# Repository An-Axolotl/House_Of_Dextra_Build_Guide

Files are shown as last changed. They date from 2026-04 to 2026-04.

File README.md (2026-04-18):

# 🏡 House of Dextra 🦾

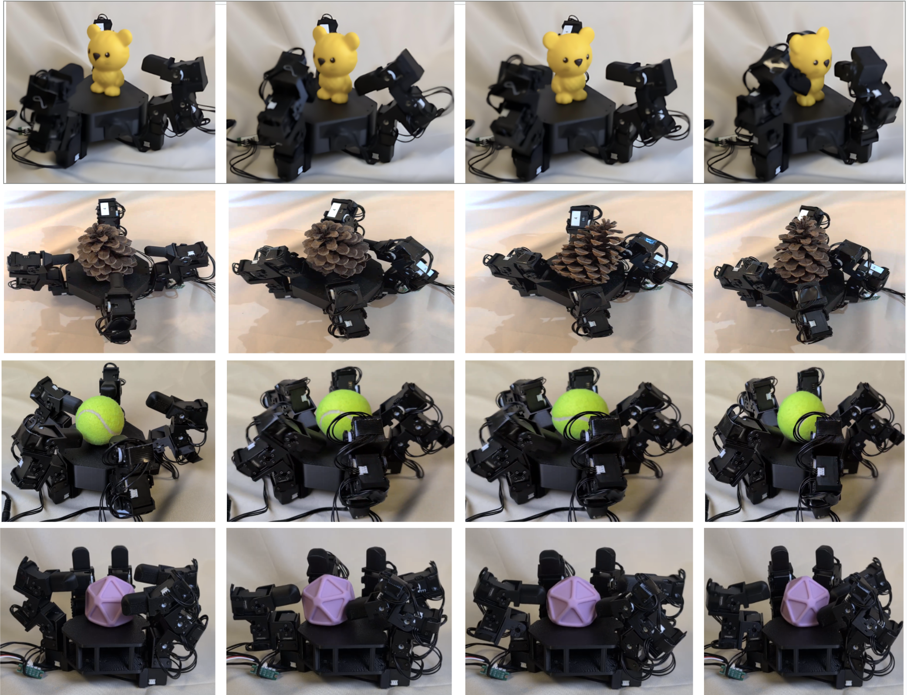
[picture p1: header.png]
House of Dextra


You can build multiple hands from one platform, here's the guide!

This guide covers how to build a modular robot hand, and how to alter it to build similar hands. Hand variants are shown on our [website](https://an-axolotl.github.io/HouseofDextra/build_guide).

**Key Features:**
- **Modular:** all electronics and components can be disassembled and re-used into other morphologies. If you are doing co-design or want to quickly prototype changes to robot hands, this is a great starting point
- **Easy to Build:** 3-4 hours to build and deploy the first hand, then less than an hour after printing for each additional robot hand
- **5 Finger Direct Drive:** 5 fingered robot hands (or 3, 4, 5, 6 fingers if you choose). Servo motors allow for easy sim-to-real since the encoders are position accurate

---

## 🛒 Bill of Materials

| Item | Quantity | Price | Notes |
|---|---|---|---|
| [Cables](https://robotis.us/robot-cable-x3p-180mm-10pcs/) | 1 | $38.42 | |
| [Expansion Boards](https://www.robotis.us/3p-jst-expansion-board/) | 2 | $13.80 | |
| [Servo Motors](https://www.robotis.us/dynamixel-xl330-m288-t/) | 20 | $549.80 | 5 finger = 20, 4 fingers = 16, 3 fingers = 12, etc. |
| [U2D2 Power Hub Board](https://www.robotis.us/u2d2-power-hub-boardset/) | 1 | $21.85 | |
| [U2D2 Communication Board](https://www.robotis.us/u2d2/) | 1 | $36.92 | |
| [Power Supply](https://www.amazon.com/ALITOVE-Converter-5-5x2-1mm-100V-240V-Security/dp/B078RT3ZPS) | 1 | $16.49 | |
| [Black PLA](https://us.store.bambulab.com/products/pla-basic-filament) | 1 | $22.99 | Makes it look cool |
| USB 3.0 | 1 | | |
| **Total** | | **$700.27** | |

**Additional tools:** Electrical tape, screwdriver kit, micro cutters (~$31). And a 3D printer that can print PLA 🤖

> **Optional:** For extra-sturdy joints, add [servo horns](https://www.robotis.us/hnx330-n101-set/) for each servo motor.

---

## 🖨️ Print Guide

Use **PLA Basic** with **auto tree branching supports** enabled. All STL files and SolidWorks parts are available **[HERE](#)** *(attach link)*.

| Part | Quantity |
|---|---|
| Palm | 1 |
| Fingertips | 5 |
| Servo Holders (connecting finger joints) | 15 |
| Lever Holders (mounting fingers to palm) | 5 |
| Servo Washers, Large | 15 |
| Servo Washers, Small | 15 |

When printing is done, remove supports with micro cutters.

---

## 🔧 Assembly

Full assembly instructions with images are at **[the build guide](https://an-axolotl.github.io/HouseofDextra/build_guide)**. At a high level:

1. Connect one servo motor vertically to the L-shaped servo holder
2. Bolt servos into each servo holder (long side down, wire ports exposed)
3. Snap large and small washers together (small inside large) and slide onto the free side of each servo
4. Mount fingertips to the top using the same process
5. Daisy-chain servo motors with X3P cables; secure wires with electrical tape
6. Bolt each assembled finger into the palm's square brackets
7. Connect four fingers to the expansion board and one directly to the U2D2 board
8. Bolt the U2D2 communication hub to the U2D2 power board, connect with one cable
9. Check wiring, plug in power, and turn on

---

## 🚀 Deployment

Install [Dynamixel Wizard](https://emanual.robotis.com/docs/en/software/dynamixel/dynamixel_wizard2/) and connect the U2D2 board via USB 3.0. Run a scan to find all motors, then:

1. **ID each motor** - number them 1-20 starting with the thumb's vertical motor as 1, working up and around each finger
2. **Verify movement** - use the torque slider in Dynamixel Wizard to confirm each motor moves
3. **Tune PID values** - go to Options and set proportional, integral, and derivative values per motor
4. **Set joint limits** - record the servo tick at each desired limit and enter them in the config file (or use the defaults provided in the code)

---

## 💻 Software

### Dependencies

```bash
pip install dynamixel-sdk numpy torch
```

Requires Python 3.8+. Motors communicate over USB via the U2D2 board (`/dev/ttyUSB0` on Linux/Mac, `COM*` on Windows).

---

### `test.py` - Hardware Verification

**Start here.** Verifies motor communication and movement without any policy. Runs a wave motion by default, where each finger bends inward then returns to rest in sequence.

```bash
python test.py --config config/anthro_standard.yaml --test-mode wave
```

**Test modes** (switch live with keyboard):

| Key | Mode | Behavior |
|-----|---|---|
| `1` | `static` | Hold default pose |
| `2` | `wave` | Wave fingers sequentially (default) |
| `3` | `sine` | Smooth sinusoidal motion on all joints |
| `4` | `incremental` | Step through predefined poses |
| `r` | | Reset to base pose |
| `Space` | | Pause / resume |
| `q` / `ESC` | | Quit (returns to base pose, disables torque) |

```
--config / -c    Path to config file   (default: config/anthro_standard.yaml)
--test-mode / -t Test mode             (default: wave)
--speed / -s     Speed multiplier      (default: 1.0)
```

If all fingers move as expected, you are good to go.

---

### `sync_midpoint_control.py` - Midpoint Oscillation Test

A self-contained lower-level test with no config file. On each keypress, toggles all finger joint motors between their midpoint and lower limit. Useful for quickly checking motor limits and PID response right after first wiring.

```bash
python sync_midpoint_control.py
```

Press any key to toggle; press `ESC` to exit. Motor IDs, limit offsets, and PID gains are hardcoded at the top of the file, edit them directly to match your hand.

> The 5 base/abduction motors (IDs 1, 5, 9, 13, 17) are held at their midpoint throughout; only the finger joint motors oscillate.

---

### `standard_control.py` - Policy Control

This script is the blueprint for running your own sim-to-real policy on the hardware. It handles the full real-time control loop: reading joint positions at the configured frequency, building a history observation, running inference on a TorchScript policy, and sending goal positions back to the motors. If you have trained a policy in simulation and want to deploy it on the hand, this is the file to adapt.

```bash
python standard_control.py \
  --config config/anthro_standard.yaml \
  --policy-path path/to/policy.pt
```

```
--config / -c      Path to config file          (default: config/anthro_standard.yaml)
--policy-path / -p Path to TorchScript .pt file (default: set in config)
```

The script sends the default pose first, then waits for a keypress to activate the policy. Loop timing stats (command Hz, read Hz, bus RTT, missed ticks) are printed every second. Press `q` or `ESC` to exit cleanly, torque is disabled automatically.

---

## 🔁 How to Adapt

- **Add/remove fingers** - Do so in motor ID order to avoid re-IDing
- **Custom palms** - Copy servo mounting brackets from the SolidWorks part onto any new geometry and export as STL
- **Custom fingertips** - Design any shape and connect on top of a lever
- **More fingers** - Add another expansion board for up to 10 fingers
- **Different materials** - PETG, TPU for flex tips, etc.

All components connect and disconnect the same way as the original assembly.

---

## 📖 Citation

If you use this in your research, please cite:

```bibtex
@article{fay2025crossembodied,
  title={House of Dextra: Cross Embodied Co-Design for Dexterous Hands},
  author={Fay, Kehlani and Djapri, Darin and Zorin, Anya and Clinton, James
          and El Lahib, Ali and Su, Hao and Tolley, Michael T. and Yi, Sha
          and Wang, Xiaolong},
  journal={arXiv preprint},
  year={2025},
  month={December}
}
```

---

*All the best, Fay* 🤖

## Motor Position Resolution
Each position tick represents 360°/4096 ≈ 0.088 degrees of rotation.

<details>
<summary><strong>Detailed Motor Configuration Settings</strong></summary>

### Motor Settings Used in Research

**Common Parameters for All Motors:**
- Moving Threshold: 10 (2.29 rev/min, unit is 0.22888 rev/min)
- Temperature Limit: 70°C
- Voltage Range: 3.5V - 7V
- PWM Limit: 100%
- Current Limit: 1750 mA
- Velocity Limit: 445 (101.85 rev/min, unit is 0.22888 rev/min)

---

#### Thumb Motors

**Motor 1:**
- Homing Offset: 0
- Min Limit: 1404 (actual: 856)
- Max Limit: 2315 (actual: 2956)
- Drive Mode: 1
- PID Gains: (1200, 100, 1500)
- Limit Offset: (+548, -641)

**Motor 2:**
- Homing Offset: 0
- Min Limit: 2048 (actual: 1990)
- Max Limit: 3072 (actual: 3370)
- Drive Mode: 1
- PID Gains: (1200, 0, 1500)
- Limit Offset: (+58, -298)

**Motor 3:**
- Homing Offset: 0
- Min Limit: 2048 (actual: 1990)
- Max Limit: 3072 (actual: 3320)
- Drive Mode: 1
- PID Gains: (2500, 0, 3000)
- Limit Offset: (+58, -248)

**Motor 4:**
- Homing Offset: 0
- Min Limit: 2048 (actual: 1990)
- Max Limit: 3072 (actual: 3340)
- Drive Mode: 1
- PID Gains: (2000, 0, 2000)
- Limit Offset: (+58, -268)

---

#### Index Finger Motors

**Motor 5:**
- Homing Offset: 0
- Min Limit: 2616 (actual: 2048)
- Max Limit: 3527 (actual: 4095)
- Drive Mode: 0
- PID Gains: (900, 180, 1500)
- Limit Offset: (+568, -568)

**Motor 6:**
- Homing Offset: 0
- Min Limit: 1024 (actual: 950)
- Max Limit: 2048 (actual: 2300)
- Drive Mode: 1
- PID Gains: (1200, 0, 2000)
- Limit Offset: (+74, -252)

**Motor 7:**
- Homing Offset: 0
- Min Limit: 2048 (actual: 1980)
- Max Limit: 3072 (actual: 3320)
- Drive Mode: 1
- PID Gains: (2500, 0, 6000)
- Limit Offset: (+68, -248)

**Motor 8:**
- Homing Offset: 0
- Min Limit: 2048 (actual: 2000)
- Max Limit: 3072 (actual: 3350)
- Drive Mode: 1
- PID Gains: (2000, 0, 2000)
- Limit Offset: (+48, -278)

---

#### Middle Finger Motors

**Motor 9:**
- Homing Offset: 0
- Min Limit: 1592 (actual: 1024)
- Max Limit: 2503 (actual: 3072)
- Drive Mode: 0
- PID Gains: (900, 0, 1500)
- Limit Offset: (+568, -569)

**Motor 10:**
- Homing Offset: 0
- Min Limit: 1024 (actual: 940)
- Max Limit: 2048 (actual: 2320)
- Drive Mode: 1
- PID Gains: (2500, 100, 6000)
- Limit Offset: (+84, -272)

**Motor 11:**
- Homing Offset: 0
- Min Limit: 2048 (actual: 1990)
- Max Limit: 3072 (actual: 3320)
- Drive Mode: 1
- PID Gains: (2000, 10, 2500)
- Limit Offset: (+58, -248)

**Motor 12:**
- Homing Offset: 0
- Min Limit: 2048 (actual: 1996)
- Max Limit: 3072 (actual: 3342)
- Drive Mode: 1
- PID Gains: (2000, 0, 2000)
- Limit Offset: (+52, -270)

---

#### Ring Finger Motors

**Motor 13:**
- Homing Offset: 0
- Min Limit: 1820 (actual: 1251)
- Max Limit: 2730 (actual: 3299)
- Drive Mode: 1
- PID Gains: (1500, 0, 1500)
- Limit Offset: (+569, -569)

**Motor 14:**
- Homing Offset: 0
- Min Limit: 1024 (actual: 960)
- Max Limit: 2048 (actual: 2300)
- Drive Mode: 1
- PID Gains: (2500, 100, 6000)
- Limit Offset: (+64, -252)

**Motor 15:**
- Homing Offset: 0
- Min Limit: 2048 (actual: 1990)
- Max Limit: 3072 (actual: 3320)
- Drive Mode: 1
- PID Gains: (2000, 10, 2500)
- Limit Offset: (+58, -248)

**Motor 16:**
- Homing Offset: 0
- Min Limit: 0 (actual: 0)
- Max Limit: 1024 (actual: 1300)
- Drive Mode: 1
- PID Gains: (2000, 0, 2000)
- Limit Offset: (0, -266)

---

#### Pinky Finger Motors

**Motor 17:**
- Homing Offset: 512
- Min Limit: 374 (actual: 0)
- Max Limit: 1285 (actual: 1854)
- Drive Mode: 0
- PID Gains: (1500, 0, 1500)
- Limit Offset: (+374, -569)

**Motor 18:**
- Homing Offset: 0
- Min Limit: 3072 (actual: 3000)
- Max Limit: 4095 (actual: 4095)
- Drive Mode: 1
- PID Gains: (2500, 100, 6000)
- Limit Offset: (+72, 0)

**Motor 19:**
- Homing Offset: 0
- Min Limit: 1024 (actual: 1285)
- Max Limit: 2048 (actual: 1787)
- Drive Mode: 1
- PID Gains: (2000, 0, 2500)
- Limit Offset: (0, -261)

**Motor 20:**
- Homing Offset: 0
- Min Limit: 2048 (actual: 1990)
- Max Limit: 3072 (actual: 3350)
- Drive Mode: 1
- PID Gains: (2000, 0, 2000)
- Limit Offset: (+98, -328)

</details>

# Installation
Run ```sudo python python/setup.py install```

# Usage
Verify control movement with ```python sync_midpoint_control.py```

Run policy with ```python run.py```

Specify a policy with ```python run.py --policy-path agents/<.pt>``` or with short form ```python run.py -p agents/<.pt>```

See more options with ```python run.py --help```

# Configuration
All configs can be found in config/config.yaml

Device name can be figured out by running:
```
pip install arduino-cli
arduino-cli core update-index
arduino-cli core install arduino:avr
arduino-cli core list
arduino-cli board list
```

# Note On Robustness
Running the policy on the real hand requires a specific default joint position that the policy was trained under. Number of observations also matters and for now these are the only observations:
1. 3 frames of <joint position normalized between [-1, 1], joint target position in radian space> 
2. One hot encoded vector for the object type between [Sphere, Cross, Cube, Cylinder]
3. Optional: Object state

Current code will need to be modified to allow for robust observation/action space based on hand design.

Also the LEAP Hand Authors chose to use the first part of the frame in [-1, 1] space while the second part is in radians space, so this may have to be changed soon too.

# References
SDK Python Scripts: 
https://emanual.robotis.com/docs/en/software/dynamixel/dynamixel_sdk/sample_code/python_read_write_protocol_2_0/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

SDK API REFERENCE:
https://emanual.robotis.com/docs/en/software/dynamixel/dynamixel_sdk/api_reference/python/

Python SDK Quick Start Guide:
https://www.youtube.com/watch?v=LAizFTTdL8o

Python SDK Walkthrough:
https://www.youtube.com/watch?v=uHnrLVZEGi4
https://www.youtube.com/watch?v=pZmueNctY0s

# Dynamixel SDK


The ROBOTIS Dynamixel SDK is a software development kit that provides Dynamixel control functions using packet communication. The API is designed for Dynamixel actuators and Dynamixel-based platforms. For more information on Dynamixel SDK, please refer to the e-manual below.
- [ROBOTIS e-Manual for Dynamixel SDK](http://emanual.robotis.com/docs/en/software/dynamixel/dynamixel_sdk/overview/)

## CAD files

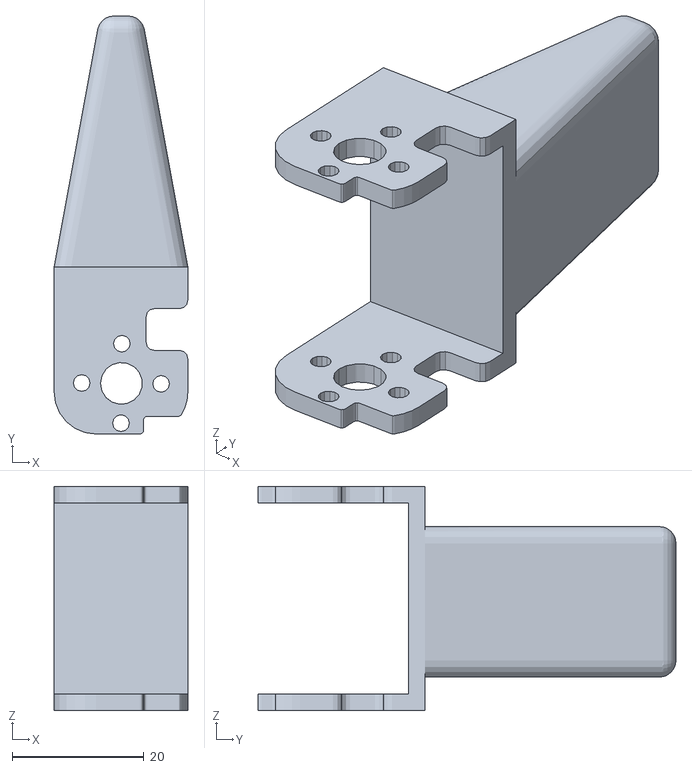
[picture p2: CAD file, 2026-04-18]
Robot_Hand_STLs/Modular Robot Hand Parts/Fingertip Options/Fingertip_Assem_Wedge.STL
20.3 x 63.5 x 34.0

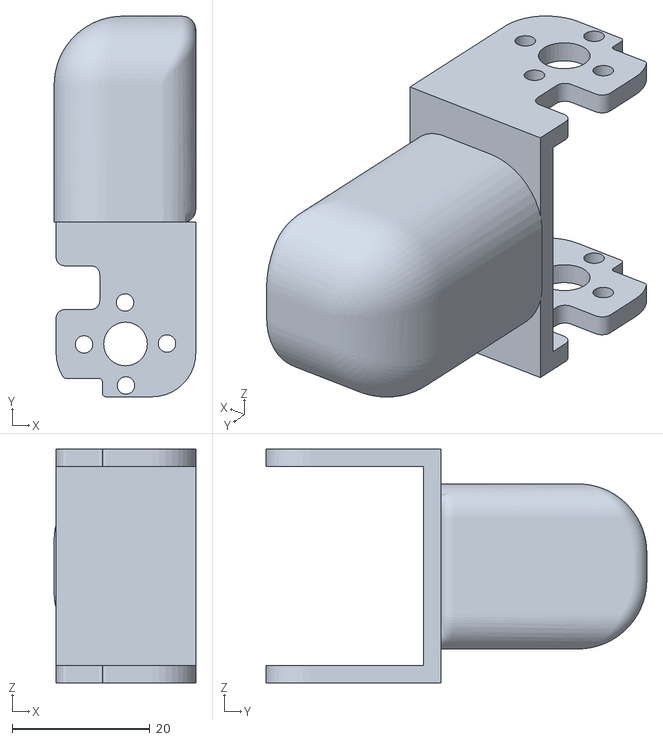
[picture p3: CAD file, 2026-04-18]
Robot_Hand_STLs/Modular Robot Hand Parts/Fingertip Options/Fingertips_Merged_from_LEAP/Fingertip_AssemLeap.STL
20.6 x 55.4 x 34.0

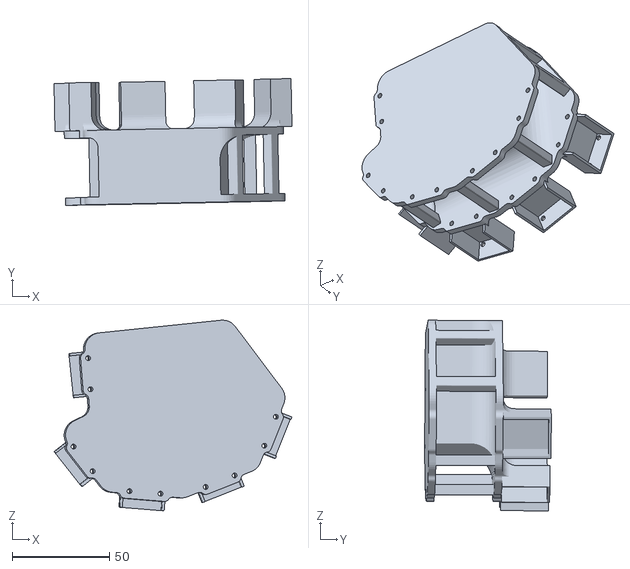
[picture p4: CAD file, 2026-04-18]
Robot_Hand_STLs/Modular Robot Hand Parts/Palm_assem.STL
122.2 x 65.1 x 97.9

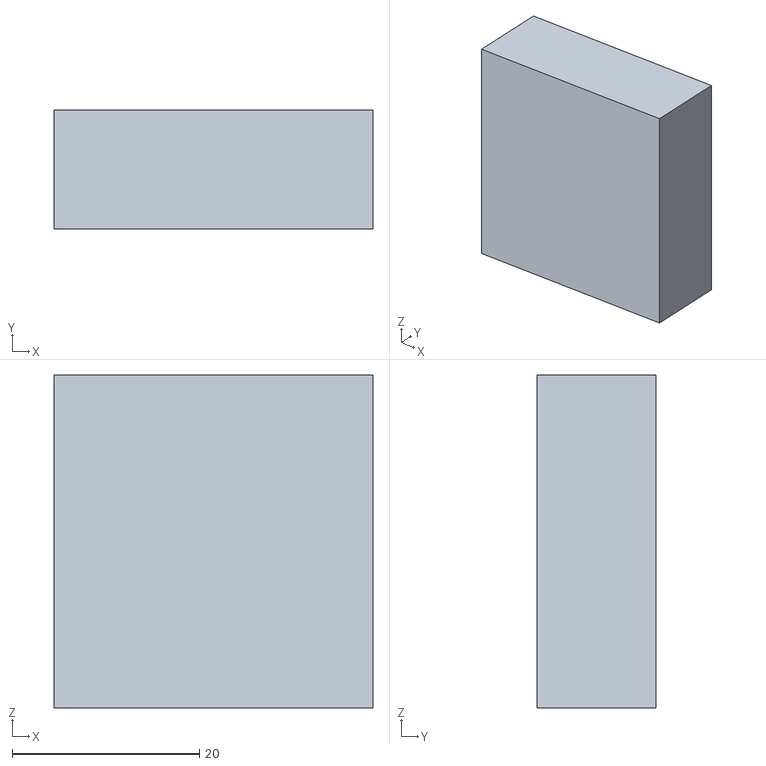
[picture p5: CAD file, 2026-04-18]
Robot_Hand_STLs/Solidworks Parts for Altering/Grammar_Rectangle (3).STL
34.0 x 12.7 x 35.6

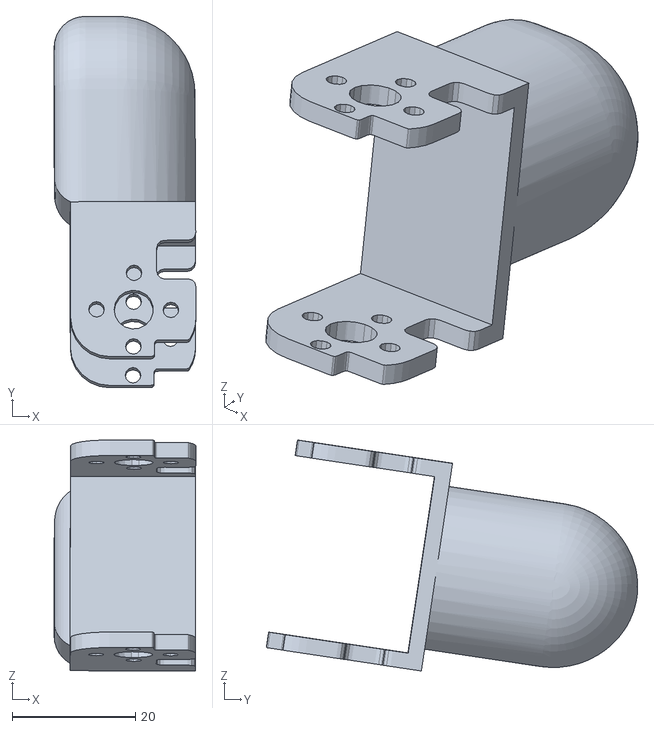
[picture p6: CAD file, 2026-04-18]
Robot_Hand_STLs/Modular Robot Hand Parts/Fingertip Options/Fingertip_Assem_Round.STL
23.0 x 60.2 x 37.5

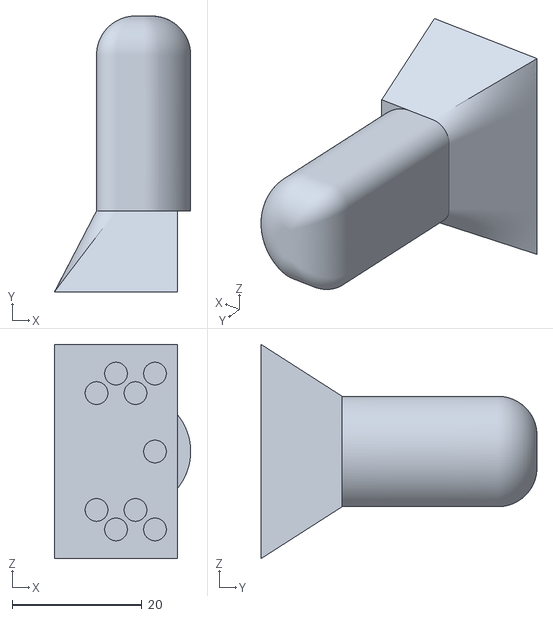
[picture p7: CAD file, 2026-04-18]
Robot_Hand_STLs/Modular Robot Hand Parts/Fingertip Options/Fingertips_Merged_from_LEAP/thinner_finger_tip(1).stl
21.0 x 42.5 x 33.0

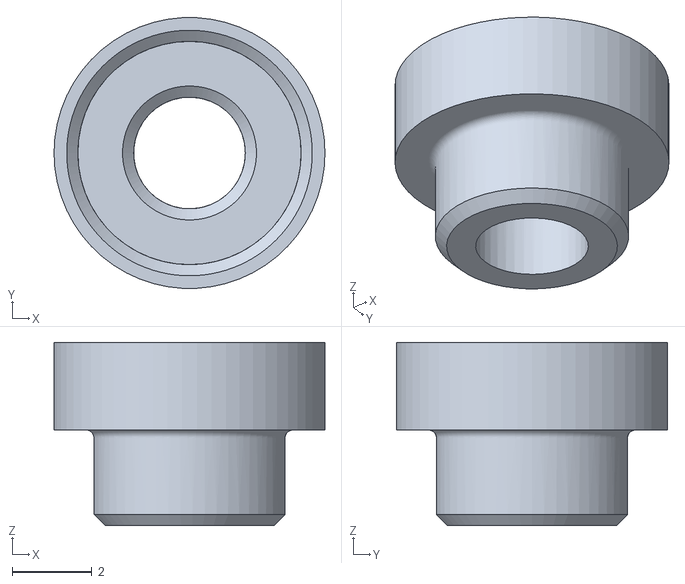
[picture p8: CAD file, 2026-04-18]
Robot_Hand_STLs/Modular Robot Hand Parts/Idler Cap.STL
6.80 x 6.79 x 4.60

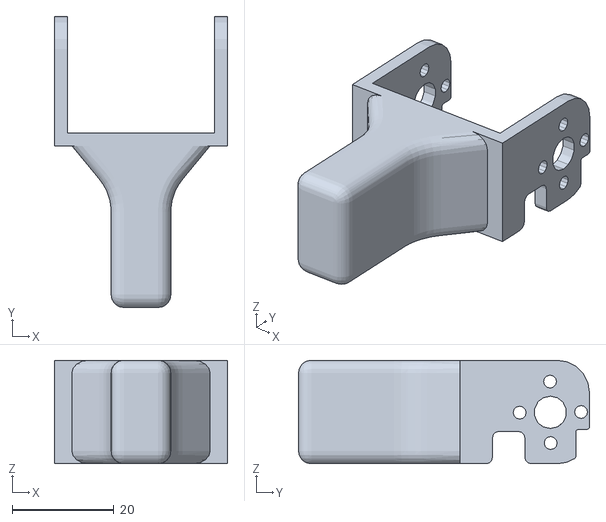
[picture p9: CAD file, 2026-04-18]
Robot_Hand_STLs/Modular Robot Hand Parts/Fingertip Options/Fingertip_Assem_Long.STL
34.0 x 57.2 x 20.3

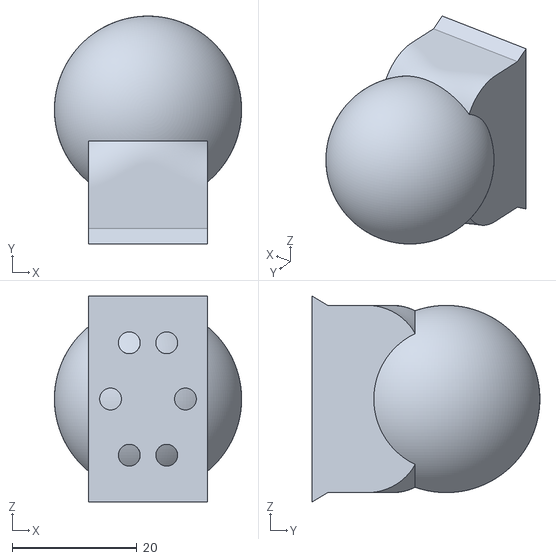
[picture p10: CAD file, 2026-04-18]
Robot_Hand_STLs/Modular Robot Hand Parts/Fingertip Options/Fingertips_Merged_from_LEAP/round_finger_tip.stl
30.0 x 36.5 x 33.0

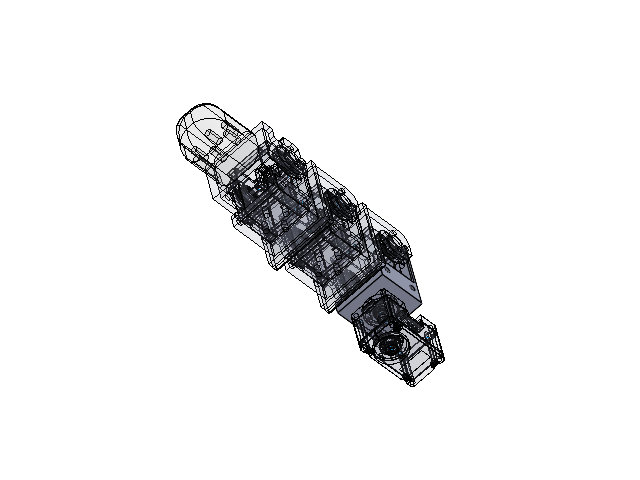
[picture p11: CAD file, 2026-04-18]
Robot_Hand_STLs/Solidworks Parts for Altering/5FingerBaseline/Finger.SLDASM
DC15_A01_CASE_M_DUMMY.stp x 4
DC15_A01_CASE_F_DUMMY.stp x 4
DC15_A01_CASE_B_DUMMY.stp x 4
DC15_A01_HORN_DUMMY.stp x 4
DC15_A01_LED_CAP2_DUMMY.stp x 4
PHS_1_7X20_5_DC10.stp x 16
BTS2_M2_6X8.stp x 8
DC15_A01_HORN_IDLE2_DUMMY.stp x 4
DC15_A01_IDLE_CAP_DUMMY.stp x 4
B3B-EH.stp x 8
finger_tip_leap
Lever_servo_fingertip_Saved
Grammar x 2
Lever_servo x 2
Servo_Bottom_Hinge x 3

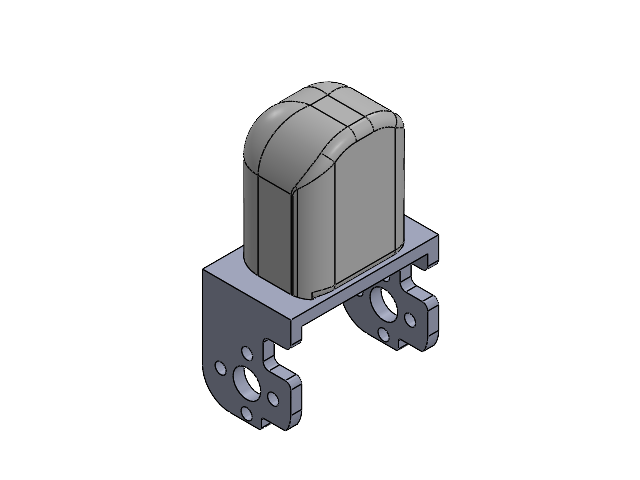
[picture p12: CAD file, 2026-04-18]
Robot_Hand_STLs/Solidworks Parts for Altering/5FingerBaseline/Fingertip_Assem.SLDASM
finger_tip_leap
Lever_servo_fingertip_Saved

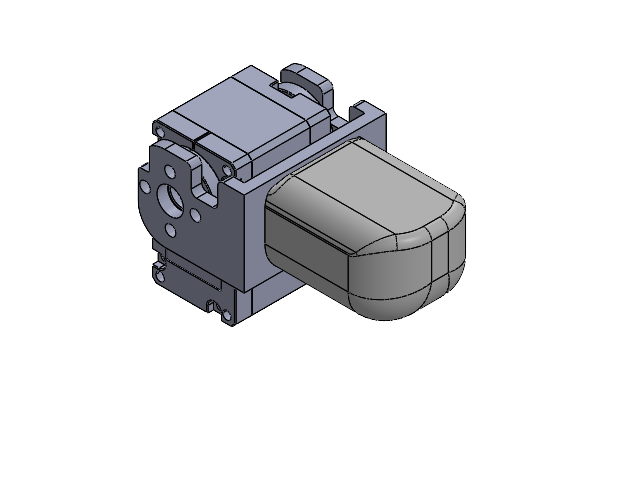
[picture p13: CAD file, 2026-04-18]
Robot_Hand_STLs/Solidworks Parts for Altering/5FingerBaseline/ServoAssem_FingerTip_Saved.SLDASM
DC15_A01_CASE_M_DUMMY.stp
DC15_A01_CASE_F_DUMMY.stp
DC15_A01_CASE_B_DUMMY.stp
DC15_A01_HORN_DUMMY.stp
DC15_A01_HORN_IDLE2_DUMMY.stp
finger_tip_leap
Lever_servo_fingertip_Saved

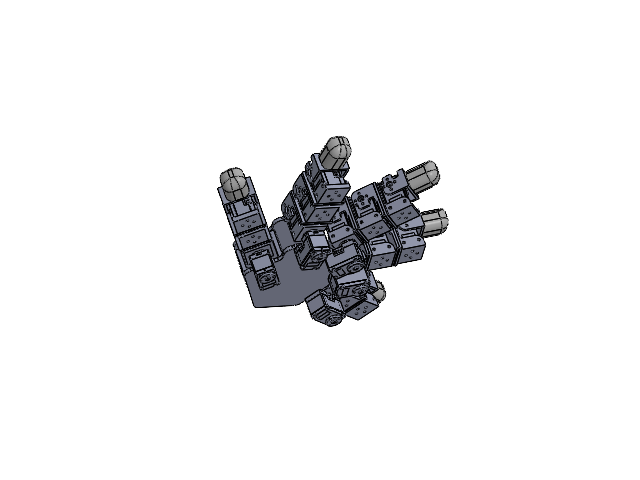
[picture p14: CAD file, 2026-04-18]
Robot_Hand_STLs/Solidworks Parts for Altering/5FingerBaseline/Modular_Lego_Assem.SLDASM
Palm_Plate_Bottom x 2
StandOff_Palm x 8
Part1^Palm_assem
DC15_A01_CASE_M_DUMMY.stp x 20
DC15_A01_CASE_F_DUMMY.stp x 20
DC15_A01_CASE_B_DUMMY.stp x 20
DC15_A01_HORN_DUMMY.stp x 20
DC15_A01_LED_CAP2_DUMMY.stp x 20
PHS_1_7X20_5_DC10.stp x 80
BTS2_M2_6X8.stp x 40
DC15_A01_HORN_IDLE2_DUMMY.stp x 20
DC15_A01_IDLE_CAP_DUMMY.stp x 20
B3B-EH.stp x 40
finger_tip_leap x 5
Lever_servo_fingertip_Saved x 5
Grammar x 10
Lever_servo x 10
Servo_Bottom_Hinge x 15

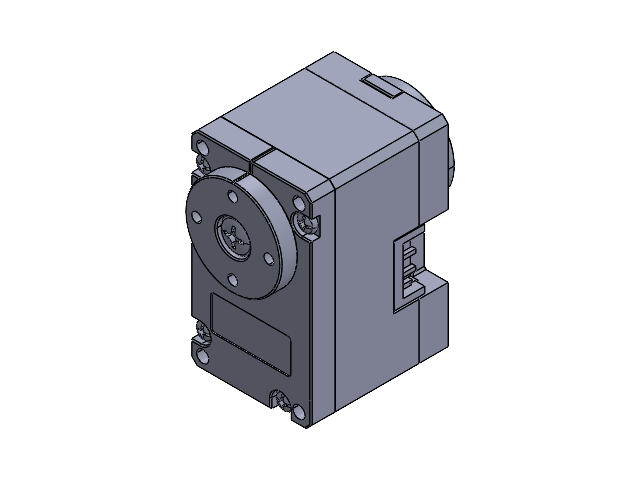
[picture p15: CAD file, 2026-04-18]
Robot_Hand_STLs/Solidworks Parts for Altering/5FingerBaseline/XL-330.SLDASM
DC15_A01_CASE_M_DUMMY.stp
DC15_A01_CASE_F_DUMMY.stp
DC15_A01_CASE_B_DUMMY.stp
DC15_A01_HORN_DUMMY.stp
DC15_A01_LED_CAP2_DUMMY.stp
PHS_1_7X20_5_DC10.stp x 4
BTS2_M2_6X8.stp x 2
DC15_A01_HORN_IDLE2_DUMMY.stp
DC15_A01_IDLE_CAP_DUMMY.stp
B3B-EH.stp x 2

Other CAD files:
Robot_Hand_STLs/Solidworks Parts for Altering/5FingerBaseline/CombineJointAssem.SLDASM
Robot_Hand_STLs/Solidworks Parts for Altering/5FingerBaseline/XL-330-228-Corrected.SLDASM
Robot_Hand_STLs/Solidworks Parts for Altering/5FingerBaseline/Palm_assem.SLDASM
Robot_Hand_STLs/Solidworks Parts for Altering/5FingerBaseline/ServoAssem_Missing_hinge.SLDASM
Robot_Hand_STLs/Modular Robot Hand Parts/Idler Horn.STL
Robot_Hand_STLs/Modular Robot Hand Parts/Servo_Bottom_Hinge.STL
Robot_Hand_STLs/Modular Robot Hand Parts/Servo_Holders(CombineJointAssem).STL
Robot_Hand_STLs/Solidworks Parts for Altering/5FingerBaseline/Grammar.SLDPRT
Robot_Hand_STLs/Solidworks Parts for Altering/5FingerBaseline/Lever_servo.SLDPRT
Robot_Hand_STLs/Solidworks Parts for Altering/5FingerBaseline/Lever_servo_fingertip_Saved.SLDPRT
Robot_Hand_STLs/Solidworks Parts for Altering/5FingerBaseline/Palm_Plate_Bottom.SLDPRT
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

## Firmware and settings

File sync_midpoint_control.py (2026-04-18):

#!/usr/bin/env python
# -*- coding: utf-8 -*-

################################################################################
# Copyright 2017 ROBOTIS CO., LTD.
#
# Licensed under the Apache License, Version 2.0 (the "License");
# you may not use this file except in compliance with the License.
# You may obtain a copy of the License at
#
#     http://www.apache.org/licenses/LICENSE-2.0
#
# Unless required by applicable law or agreed to in writing, software
# distributed under the License is distributed on an "AS IS" BASIS,
# WITHOUT WARRANTIES OR CONDITIONS OF ANY KIND, either express or implied.
# See the License for the specific language governing permissions and
# limitations under the License.
################################################################################


#*******************************************************************************
#***********************     SyncRead and SyncWrite Example      ***********************
#  Required Environment to run this example :
#    - Protocol 2.0 supported DYNAMIXEL(X, P, PRO/PRO(A), MX 2.0 series)
#    - DYNAMIXEL Starter Set (U2D2, U2D2 PHB, 12V SMPS)
#  How to use the example :
#    - Select the DYNAMIXEL in use at the MY_DXL in the example code. 
#    - Build and Run from proper architecture subdirectory.
#    - For ARM based SBCs such as Raspberry Pi, use linux_sbc subdirectory to build and run.
#    - https://emanual.robotis.com/docs/en/software/dynamixel/dynamixel_sdk/overview/
#  Author: Ryu Woon Jung (Leon)
#  Maintainer : Zerom, Will Son
# *******************************************************************************

import os
import sys, tty, termios, select
import time

if os.name == 'nt':
    import msvcrt
    def getch():
        return msvcrt.getch().decode()
else:
    import sys, tty, termios
    fd = sys.stdin.fileno()
    old_settings = termios.tcgetattr(fd)
    def getch(block=True, timeout=None, flush=False):
        fd = sys.stdin.fileno()
        old = termios.tcgetattr(fd)
        try:
            sys.stdout.flush()
            if flush:
                termios.tcflush(fd, termios.TCIFLUSH)  # only when blocking prompt
            tty.setcbreak(fd)
            if block and timeout is None:
                return sys.stdin.read(1)
            r, _, _ = select.select([fd], [], [], 0 if timeout is None else timeout)
            return sys.stdin.read(1) if r else None
        finally:
            termios.tcsetattr(fd, termios.TCSADRAIN, old)


from dynamixel_sdk import *                    # Uses Dynamixel SDK library

# Control table address
ADDR_TORQUE_ENABLE          = 64
ADDR_GOAL_POSITION          = 116
LEN_GOAL_POSITION           = 4         # Data Byte Length
ADDR_PRESENT_POSITION       = 132
LEN_PRESENT_POSITION        = 4         # Data Byte Length
ADDR_MIN_POSITION_LIMIT     = 52
ADDR_MAX_POSITION_LIMIT     = 48
ADDR_PROFILE_VELOCITY       = 112
ADDR_PROFILE_ACCELERATION   = 108
ADDR_POSITION_P_GAIN        = 84
ADDR_POSITION_I_GAIN        = 82
ADDR_POSITION_D_GAIN        = 80
ADDR_FIRMWARE_VERSION       = 6
ADDR_RETURN_DELAY_TIME      = 9

DXL_MINIMUM_POSITION_VALUE  = 0         # Refer to the Minimum Position Limit of product eManual
DXL_MAXIMUM_POSITION_VALUE  = 4095      # Refer to the Maximum Position Limit of product eManual
BAUDRATE                    = 3000000

# DYNAMIXEL Protocol Version (1.0 / 2.0)
# https://emanual.robotis.com/docs/en/dxl/protocol2/
PROTOCOL_VERSION            = 2.0

# Motor configuration
DXL_ID_ALL_CNT = 20
DXL_ID_ALL = [1, 2, 3, 4, 5, 6, 7, 8, 9, 10, 11, 12, 13, 14, 15, 16, 17, 18, 19, 20]

# # Per-ID limit offsets for tighter limits: {tight_lo_offset, tight_hi_offset}
# LIMIT_OFFSETS = [
#     [+618, -458],  # ID 1
#     [+58, -298],   # ID 2
#     [+58, -248],   # ID 3
#     [+58, -268],   # ID 4
#     [+682, -682],  # ID 5
#     [+74, -252],   # ID 6
#     [+68, -248],   # ID 7
#     [+48, -278],   # ID 8
#     [+682, -682],  # ID 9
#     [+84, -272],   # ID 10
#     [+58, -248],   # ID 11
#     [+52, -270],   # ID 12
#     [+172, -171],  # ID 13
#     [+64, -252],   # ID 14
#     [+58, -248],   # ID 15
#     [0, -266],    # ID 16
#     [+322, -489],   # ID 17
#     [72,  0],   # ID 18
#     [0,  -261],   # ID 19
#     [98,  -328]    # ID 20
# ]

LIMIT_OFFSETS = [
  [23, -533],   # ID 1
  [16, -261],    # ID 2
  [17, -114],    # ID 3
  [273, -114],    # ID 4
  [57, -228],   # ID 5
  [34, -284],    # ID 6
  [34, -114],    # ID 7
  [228, -171],    # ID 8
  [57, -114],   # ID 9
  [34, -284],    # ID 10
  [34, -114],    # ID 11
  [228, -171],    # ID 12
  [148, -80],   # ID 13
  [11, -341],    # ID 14
  [23, -114],    # ID 15
  [228, -171],     # ID 16
  [604, -250],   # ID 17
  [23, -341],       # ID 18
  [34, -125],     # ID 19
  [228, -171]     # ID 20
]

# # PID Gains [P, I, D]
# DXL_PID_GAINS = [
#     [1200, 100, 1500], # ID 0 - Thumb Motor 0
#     [1200, 0, 1500],   # ID 1 - Thumb Motor 1 
#     [2500, 0, 3000],   # ID 2 - Thumb Motor 2
#     [2000, 0, 2000],   # ID 3 - Thumb Motor 3
#     [900, 180, 1500],  # ID 4 - Index Motor 4
#     [1200, 0, 2000],   # ID 5 - Index Motor 5
#     [2500, 0, 6000],   # ID 6 - Index Motor 6
#     [2000, 0, 2000],   # ID 7 - Index Motor 7
#     [900, 0, 1500],    # ID 8
#     [2500, 100, 6000], # ID 9
#     [2000, 10, 2500],  # ID 10
#     [2000, 0, 2000],   # ID 11
#     [1500, 0, 1500],   # ID 12
#     [2500, 100, 6000], # ID 13
#     [2000, 10, 2500],  # ID 14
#     [2000, 0, 2000],   # ID 15
#     [1500, 0, 1500],   # ID 16
#     [2500, 100, 6000], # ID 17
#     [2000, 0, 2500],   # ID 18
#     [2000, 0, 2000]    # ID 19
# ]

DXL_PID_GAINS = [
  [700, 0, 400],  # ID 1
  [750, 40, 400],    # ID 2
  [700, 20, 400],    # ID 3
  [750, 0, 400],    # ID 4
  [700, 0, 400],   # ID 5
  [750, 15, 450],    # ID 6
  [800, 5, 400],    # ID 7
  [750, 0, 400],    # ID 8
  [700, 0, 450],     # ID 9
  [700, 50, 400],  # ID 10
  [775, 0, 450],   # ID 11
  [700, 0, 400],    # ID 12
  [700, 0, 400],    # ID 13
  [750, 15, 400],  # ID 14
  [800, 30, 500],   # ID 15
  [600, 0, 200],    # ID 16
  [800, 0, 550],    # ID 17
  [800, 0, 400],  # ID 18
  [800, 0, 450],    # ID 19
  [800, 0, 450]     # ID 20
]

# Motors to actually move (only 2 and 3)
# DXL_ID_MOVE = [15]
DXL_ID_MOVE = [2, 3, 4, 6, 7, 8, 10, 11, 12, 14, 15, 16, 18, 19, 20]

# DXL_ID_MIDDLE = []
DXL_ID_MIDDLE = [1, 5, 9, 13, 17]



# Use the actual port assigned to the U2D2.
# ex) Windows: "COM*", Linux: "/dev/ttyUSB*", Mac: "/dev/tty.usbserial-*"
DEVICENAME                  = '/dev/ttyUSB0'

TORQUE_ENABLE               = 1                 # Value for enabling the torque
TORQUE_DISABLE              = 0                 # Value for disabling the torque
DXL_MOVING_STATUS_THRESHOLD = 20                # Dynamixel moving status threshold

# Store limits for each motor
motor_limits = {}

index = 0

# Initialize PortHandler instance
# Set the port path
# Get methods and members of PortHandlerLinux or PortHandlerWindows
portHandler = PortHandler(DEVICENAME)

# Initialize PacketHandler instance
# Set the protocol version
# Get methods and members of Protocol1PacketHandler or Protocol2PacketHandler
packetHandler = PacketHandler(PROTOCOL_VERSION)

# Initialize GroupSyncWrite instance
groupSyncWrite = GroupSyncWrite(portHandler, packetHandler, ADDR_GOAL_POSITION, LEN_GOAL_POSITION)

# Initialize GroupSyncRead instace for Present Position
groupSyncRead = GroupSyncRead(portHandler, packetHandler, ADDR_PRESENT_POSITION, LEN_PRESENT_POSITION)

# Open port
if portHandler.openPort():
    print("Succeeded to open the port")
else:
    print("Failed to open the port")
    print("Press any key to terminate...")
    getch()
    quit()

# Set port baudrate
if portHandler.setBaudRate(BAUDRATE):
    print("Succeeded to change the baudrate")
else:
    print("Failed to change the baudrate")
    print("Press any key to terminate...")
    getch()
    quit()

# Check SDK support + firmware gate for Fast Sync Read (X/XL-330 need fw >= 46)
def all_fw_ok(ids):
    for i in ids:
        fw, _, _ = packetHandler.read1ByteTxRx(portHandler, i, ADDR_FIRMWARE_VERSION)
        if fw is None or fw < 46:
            return False
    return True

FAST_API = hasattr(groupSyncRead, 'fastSyncRead')  # available in recent SDKs
FAST_OK  = FAST_API and all_fw_ok(DXL_ID_MOVE)
print("Fast Sync Read available:", FAST_OK)

# Configure all motors
for i, motor_id in enumerate(DXL_ID_ALL):
    # Disable torque first
    packetHandler.write1ByteTxRx(portHandler, motor_id, ADDR_TORQUE_ENABLE, TORQUE_DISABLE)
    
    # Read current limits
    min_limit, _, _ = packetHandler.read4ByteTxRx(portHandler, motor_id, ADDR_MIN_POSITION_LIMIT)
    max_limit, _, _ = packetHandler.read4ByteTxRx(portHandler, motor_id, ADDR_MAX_POSITION_LIMIT)
    
    # Calculate tight limits
    tight_lo = min_limit + LIMIT_OFFSETS[i][0]
    tight_hi = max_limit + LIMIT_OFFSETS[i][1]
    
    motor_limits[motor_id] = {
        'lo': min_limit,
        'hi': max_limit,
        'tight_lo': tight_lo,
        'tight_hi': tight_hi,
        'mid': (tight_lo + tight_hi) // 2
    }
    
    # Set PID gains
    packetHandler.write2ByteTxRx(portHandler, motor_id, ADDR_POSITION_P_GAIN, DXL_PID_GAINS[i][0])
    packetHandler.write2ByteTxRx(portHandler, motor_id, ADDR_POSITION_I_GAIN, DXL_PID_GAINS[i][1])
    packetHandler.write2ByteTxRx(portHandler, motor_id, ADDR_POSITION_D_GAIN, DXL_PID_GAINS[i][2])
    
    # Set profile velocity and acceleration
    packetHandler.write4ByteTxRx(portHandler, motor_id, ADDR_PROFILE_VELOCITY, 300)
    packetHandler.write4ByteTxRx(portHandler, motor_id, ADDR_PROFILE_ACCELERATION, 100)
    
    print(f"Configured motor {motor_id}: limits({tight_lo}-{tight_hi}), PID({DXL_PID_GAINS[i]})")

# Enable torque for motors we want to move
for motor_id in DXL_ID_MOVE:
    dxl_comm_result, dxl_error = packetHandler.write1ByteTxRx(portHandler, motor_id, ADDR_TORQUE_ENABLE, TORQUE_ENABLE)
    if dxl_comm_result != COMM_SUCCESS:
        print("%s" % packetHandler.getTxRxResult(dxl_comm_result))
    elif dxl_error != 0:
        print("%s" % packetHandler.getRxPacketError(dxl_error))
    else:
        print("Dynamixel#%d has been successfully connected" % motor_id)
        
# Enable torque and set middle position for stationary motors
for motor_id in DXL_ID_MIDDLE:
    # Enable torque
    dxl_comm_result, dxl_error = packetHandler.write1ByteTxRx(portHandler, motor_id, ADDR_TORQUE_ENABLE, TORQUE_ENABLE)
    if dxl_comm_result != COMM_SUCCESS:
        print("%s" % packetHandler.getTxRxResult(dxl_comm_result))
    elif dxl_error != 0:
        print("%s" % packetHandler.getRxPacketError(dxl_error))
    else:
        print("Dynamixel#%d enabled for middle position" % motor_id)
    
    # Set to middle position
    mid_pos = motor_limits[motor_id]['mid']
    param_middle_position = [DXL_LOBYTE(DXL_LOWORD(mid_pos)), DXL_HIBYTE(DXL_LOWORD(mid_pos)), 
                            DXL_LOBYTE(DXL_HIWORD(mid_pos)), DXL_HIBYTE(DXL_HIWORD(mid_pos))]
    
    dxl_comm_result, dxl_error = packetHandler.write4ByteTxRx(portHandler, motor_id, ADDR_GOAL_POSITION, mid_pos)
    if dxl_comm_result != COMM_SUCCESS:
        print("%s" % packetHandler.getTxRxResult(dxl_comm_result))
    elif dxl_error != 0:
        print("%s" % packetHandler.getRxPacketError(dxl_error))
    else:
        print("Dynamixel#%d set to middle position: %d" % (motor_id, mid_pos))

# Add parameter storage for motors we want to read
for motor_id in DXL_ID_MOVE:
    dxl_addparam_result = groupSyncRead.addParam(motor_id)
    if dxl_addparam_result != True:
        print("[ID:%03d] groupSyncRead addparam failed" % motor_id)
        quit()

while 1:
    print("Press any key to continue! (or press ESC to quit!)")
    ch = getch(block=True, flush=True)  # blocks until a key
    if ch == '\x1b':  # ESC
        break

    # Move only motors 2 and 3 - oscillate between midpoint and upper limit
    for motor_id in DXL_ID_MOVE:
        # Use motor-specific limits - alternate between mid and upper limit
        if index == 0:
            goal_pos = motor_limits[motor_id]['mid']
        else:
            goal_pos = motor_limits[motor_id]['tight_lo']
        
        # Allocate goal position value into byte array
        param_goal_position = [DXL_LOBYTE(DXL_LOWORD(goal_pos)), DXL_HIBYTE(DXL_LOWORD(goal_pos)), DXL_LOBYTE(DXL_HIWORD(goal_pos)), DXL_HIBYTE(DXL_HIWORD(goal_pos))]

        # Add goal position value to the Syncwrite parameter storage
        dxl_addparam_result = groupSyncWrite.addParam(motor_id, param_goal_position)
        if dxl_addparam_result != True:
            print("[ID:%03d] groupSyncWrite addparam failed" % motor_id)
            quit()

    # Syncwrite goal position
    dxl_comm_result = groupSyncWrite.txPacket()
    if dxl_comm_result != COMM_SUCCESS:
        print("%s" % packetHandler.getTxRxResult(dxl_comm_result))

    # Clear syncwrite parameter storage
    groupSyncWrite.clearParam()

    # ---- READ LOOP ----
    while True:
        # Fast Sync Read (single aggregated status packet) if supported
        dxl_comm_result = groupSyncRead.fastSyncRead() if FAST_OK else groupSyncRead.txRxPacket()
        if dxl_comm_result != COMM_SUCCESS:
            print(packetHandler.getTxRxResult(dxl_comm_result))
            continue

        positions = {}
        goals = {}
        all_reached = True

        for motor_id in DXL_ID_MOVE:
            if not groupSyncRead.isAvailable(motor_id, ADDR_PRESENT_POSITION, LEN_PRESENT_POSITION):
                print("[ID:%03d] groupSyncRead getdata failed" % motor_id)
                all_reached = False
                break

            positions[motor_id] = groupSyncRead.getData(motor_id, ADDR_PRESENT_POSITION, LEN_PRESENT_POSITION)
            goals[motor_id] = motor_limits[motor_id]['mid'] if index == 0 else motor_limits[motor_id]['tight_lo']

            if abs(goals[motor_id] - positions[motor_id]) > DXL_MOVING_STATUS_THRESHOLD:
                all_reached = False

        if all_reached:
            break

    if len(positions) == len(DXL_ID_MOVE):
        print("=== ALL MOTOR STATUS ===")
        
        # Read positions for middle motors
        middle_positions = {}
        for motor_id in DXL_ID_MIDDLE:
            dxl_present_position, dxl_comm_result, dxl_error = packetHandler.read4ByteTxRx(portHandler, motor_id, ADDR_PRESENT_POSITION)
            if dxl_comm_result == COMM_SUCCESS:
                middle_positions[motor_id] = dxl_present_position
        
        # Print all motors in ID order
        all_motor_ids = sorted(DXL_ID_MOVE + DXL_ID_MIDDLE)
        for motor_id in all_motor_ids:
            if motor_id in DXL_ID_MOVE:
                status = "MOVING"
                goal = goals[motor_id]
                present = positions[motor_id]
            else:
                status = "MIDDLE"
                goal = motor_limits[motor_id]['mid']
                present = middle_positions.get(motor_id, 0)
            
            diff = abs(goal - present)
            print(f"[ID:{motor_id:02d}] {status:6s} | Goal:{goal:4d} Present:{present:4d} Diff:{diff:3d}")
        print("=" * 50)

    # Change goal position (toggle between midpoint and upper limit)
    index = 1 - index

# Clear syncread parameter storage
groupSyncRead.clearParam()

# Disable torque for moved motors
for motor_id in DXL_ID_MOVE + DXL_ID_MIDDLE:
    dxl_comm_result, dxl_error = packetHandler.write1ByteTxRx(portHandler, motor_id, ADDR_TORQUE_ENABLE, TORQUE_DISABLE)
    if dxl_comm_result != COMM_SUCCESS:
        print("%s" % packetHandler.getTxRxResult(dxl_comm_result))
    elif dxl_error != 0:
        print("%s" % packetHandler.getRxPacketError(dxl_error))

# Close port
portHandler.closePort()

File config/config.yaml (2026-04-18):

# Default configuration for robotic hand control

# Policy Configuration
policy:
  # default_path: "agents/small_cube_no_scaling/first_success.pt"

  # default_path: "agents/small_cube_no_scaling/40min_fs1.pt"
  # default_path: "agents/small_cube_no_scaling/highest_rew_fs1_policy.pt"
  # default_path: "agents/small_cube_no_scaling/max_trained_fs1.pt"

  # default_path: "agents/first_generalized.pt"

  # default_path: "agents/small_cube_best4.pt"
  # default_path: "agents/best_small_cube.pt"
  default_path: "agents/last_small_cube.pt"
  

# Control Parameters
control:
  act_moving_avg: 0.041666666666666664  # 1.0 / 24.0
  control_hz: 30.0

# Default Joint Positions (Isaac order)
joint_positions:
  # set for small cube
  # default_isaac_order: [
  #       0.3, 0.477, 0.0, 0.0, 0.0,
  #       1.0, 0.748, 0.0, 0.0, 0.487,
  #       1.57, 1.32, 1.57, 1.57, 1.46,
  #       0.5, 0.726, 0.5, 0.5, 1.16
  #   ]

  # ????
  # default_isaac_order: [
  #   0.3, 0.477, 0.0, 0.0, 0.0,
  #   1.0, 0.487, 0.0, 0.0, 0.487,
  #   1.57, 1.32, 1.57, 1.57, 1.46,
  #   0.5, 0.726, 0.0, 0.0, 1.16
  # ]

  # generalized for scaled cubes
  # default_isaac_order: [
  #   0.3, 0.477, 0.0, 0.0, 0.0,
  #   1.0, 0.534, 0.0, 0.0, 0.487,
  #   1.57, 1.35, 1.57, 1.57, 1.46,
  #   0.5, 1.05, 0.5, 0.5, 1.16
  # ]

  # trained for modded as well as small cubes
  # default_isaac_order: [
  #   0.3, 0.477, 0.0, 0.0, 0.0,
  #   1.0, 0.534, 0.0, 0.0, 0.487,
  #   1.57, 1.35, 1.57, 1.57, 1.46,
  #   0.5, 1.05, 0.5, 0.5, 1.16
  # ]

  default_isaac_order : [
         0.0, 0.698, -0.0977, 0.23, 0.0,
         1.04, 0.848, 0.0, 0.0, 0.778,
         1.21, 0.809, 1.53, 1.57, 1.15,
         1.04, 1.35, 0.0, 0.0, 1.07,
     ]


# Dynamixel Hardware Configuration
dynamixel:
  # Communication
  device_name: "/dev/ttyUSB0"
  baudrate: 3000000
  protocol_version: 2.0
  
  # Motor IDs
  motor_ids: [1, 2, 3, 4, 5, 6, 7, 8, 9, 10, 11, 12, 13, 14, 15, 16, 17, 18, 19, 20]
  palm_ids: [1, 5, 9, 13, 17]
  
  # Control table addresses
  addresses:
    torque_enable: 64
    goal_position: 116
    present_position: 132
    min_position_limit: 52
    max_position_limit: 48
    profile_velocity: 112
    profile_acceleration: 108
    position_p_gain: 84
    position_i_gain: 82
    position_d_gain: 80
    firmware_version: 6
    return_delay_time: 9
  
  # Data lengths
  data_lengths:
    goal_position: 4
    present_position: 4
  
  # Constants
  torque_enable_value: 1
  torque_disable_value: 0
  invalid_u32: 0xFFFFFFFF
  
  # Motor configuration
  profile_velocity: 300
  profile_acceleration: 100

# Per-motor limit offsets [tight_lo_offset, tight_hi_offset]
limit_offsets: [
  [23, -533],   # ID 1
  [16, -261],    # ID 2
  [17, -114],    # ID 3
  [273, -114],    # ID 4
  [57, -228],   # ID 5
  [34, -284],    # ID 6
  [34, -114],    # ID 7
  [228, -171],    # ID 8
  [57, -114],   # ID 9
  [34, -284],    # ID 10
  [34, -114],    # ID 11
  [228, -171],    # ID 12
  [148, -80],   # ID 13
  [11, -341],    # ID 14
  [23, -114],    # ID 15
  [228, -171],     # ID 16
  [604, -250],   # ID 17
  [23, -341],       # ID 18
  [34, -125],     # ID 19
  [228, -171]     # ID 20
]

# PID Gains [P, I, D] for each motor
pid_gains: [
  [700, 0, 400],  # ID 1
  [750, 40, 400],    # ID 2
  [700, 20, 400],    # ID 3
  [750, 0, 400],    # ID 4
  [700, 0, 400],   # ID 5
  [750, 15, 450],    # ID 6
  [800, 5, 400],    # ID 7
  [750, 0, 400],    # ID 8
  [700, 0, 450],     # ID 9
  [700, 50, 400],  # ID 10
  [775, 0, 450],   # ID 11
  [700, 0, 400],    # ID 12
  [700, 0, 400],    # ID 13
  [750, 15, 400],  # ID 14
  [800, 30, 500],   # ID 15
  [600, 0, 200],    # ID 16
  [800, 0, 550],    # ID 17
  [800, 0, 400],  # ID 18
  [800, 0, 450],    # ID 19
  [800, 0, 450]     # ID 20
]

# Simulation Parameters
simulation:
  # Joint ranges for simulation
  palm_range: [-0.698, 0.698]
  other_range: [0.0, 1.5708]

# Observation Configuration
observation:
  history_frames: 3
  object_one_hot: [1, 0, 0, 0]

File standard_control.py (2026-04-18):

#!/usr/bin/env python
# -*- coding: utf-8 -*-

import os, sys, tty, termios, select, time, math
import argparse
from collections import deque
import numpy as np
import torch
from dynamixel_sdk import *

# Import utilities
from utils.config_loader import Config
from utils.transform import reorder_isaaclab_to_mujoco, reorder_mujoco_to_isaaclab, get_default_joint_positions_sim_mj
from utils.hardware_converter import HardwareConverter
from utils.input import setup_input, getch

# =========================
# Argument parsing (before loading config)
# =========================
def parse_args():
    parser = argparse.ArgumentParser(description='Run robotic hand control with policy')
    parser.add_argument('--config', '-c',
                       type=str,
                       default="config/anthro_standard.yaml",
                       help='Path to configuration file (default: config/anthro_standard.yaml)')
    parser.add_argument('--policy-path', '-p', 
                       type=str,
                       default=None,  # Will be set from config if not provided
                       help='Path to the policy file (overrides config default)')
    return parser.parse_args()

# Parse arguments first
args = parse_args()

# =========================
# Load configuration
# =========================
config = Config(args.config)

# Set policy path: command line overrides config default
if args.policy_path is None:
    TS_POLICY_PATH = config.policy_default_path
else:
    TS_POLICY_PATH = args.policy_path

print(f"Using policy: {TS_POLICY_PATH}")
print(f"Using config: {args.config}")

# =========================
# Config (policy + timing)
# =========================
ACT_MOVING_AVG = config.act_moving_avg
CONTROL_HZ = config.control_hz

# =========================
# Set up 
# =========================
hardware_converter = HardwareConverter(config)
fd, old_settings = setup_input()

# =========================
# Dynamixel constants from config
# =========================
ADDR_TORQUE_ENABLE = config.get_dynamixel_address('torque_enable')
ADDR_GOAL_POSITION = config.get_dynamixel_address('goal_position')
LEN_GOAL_POSITION = config.get_data_length('goal_position')
ADDR_PRESENT_POSITION = config.get_dynamixel_address('present_position')
LEN_PRESENT_POSITION = config.get_data_length('present_position')
ADDR_MIN_POSITION_LIMIT = config.get_dynamixel_address('min_position_limit')
ADDR_MAX_POSITION_LIMIT = config.get_dynamixel_address('max_position_limit')
ADDR_PROFILE_VELOCITY = config.get_dynamixel_address('profile_velocity')
ADDR_PROFILE_ACCELERATION = config.get_dynamixel_address('profile_acceleration')
ADDR_POSITION_P_GAIN = config.get_dynamixel_address('position_p_gain')
ADDR_POSITION_I_GAIN = config.get_dynamixel_address('position_i_gain')
ADDR_POSITION_D_GAIN = config.get_dynamixel_address('position_d_gain')
ADDR_FIRMWARE_VERSION = config.get_dynamixel_address('firmware_version')
ADDR_RETURN_DELAY_TIME = config.get_dynamixel_address('return_delay_time')

BAUDRATE = config.dynamixel_baudrate
PROTOCOL_VERSION = config.dynamixel_protocol_version

DXL_ID_ALL = config.motor_ids
DXL_ID_MOVE = DXL_ID_ALL[:]  # control all motors

# Palms are IDs from config
PALM_IDS = config.palm_ids

LIMIT_OFFSETS = config.limit_offsets
DXL_PID_GAINS = config.pid_gains

DEVICENAME = config.dynamixel_device_name
TORQUE_ENABLE = config.get('dynamixel.torque_enable_value')
TORQUE_DISABLE = config.get('dynamixel.torque_disable_value')
INVALID_U32 = config.get('dynamixel.invalid_u32')

# =========================
# Init comms
# =========================
portHandler = PortHandler(DEVICENAME)
packetHandler = PacketHandler(PROTOCOL_VERSION)
groupSyncWrite = GroupSyncWrite(portHandler, packetHandler, ADDR_GOAL_POSITION, LEN_GOAL_POSITION)
groupSyncRead = GroupSyncRead(portHandler, packetHandler, ADDR_PRESENT_POSITION, LEN_PRESENT_POSITION)

if not portHandler.openPort(): print("Failed to open the port"); sys.exit(1)
print("Succeeded to open the port")
if not portHandler.setBaudRate(BAUDRATE): print("Failed to set the baudrate"); sys.exit(1)
print("Succeeded to change the baudrate")

def all_fw_ok(ids):
    for i in ids:
        fw, _, _ = packetHandler.read1ByteTxRx(portHandler, i, ADDR_FIRMWARE_VERSION)
        if fw is None or fw < 46:
            return False
    return True
FAST_API = hasattr(groupSyncRead, 'fastSyncRead')
FAST_OK = FAST_API and all_fw_ok(DXL_ID_ALL)
print("Fast Sync Read available:", FAST_OK)

# =========================
# Configure motors + limits
# =========================
motor_limits = {}
profile_velocity = config.get('dynamixel.profile_velocity')
profile_acceleration = config.get('dynamixel.profile_acceleration')

for i, motor_id in enumerate(DXL_ID_ALL):
    packetHandler.write1ByteTxRx(portHandler, motor_id, ADDR_TORQUE_ENABLE, TORQUE_DISABLE)
    min_limit, _, _ = packetHandler.read4ByteTxRx(portHandler, motor_id, ADDR_MIN_POSITION_LIMIT)
    max_limit, _, _ = packetHandler.read4ByteTxRx(portHandler, motor_id, ADDR_MAX_POSITION_LIMIT)
    tight_lo = max(0, min(min_limit + LIMIT_OFFSETS[i][0], 4095))
    tight_hi = max(0, min(max_limit + LIMIT_OFFSETS[i][1], 4095))
    if tight_lo >= tight_hi:
        center = (min_limit + max_limit) // 2
        tight_lo, tight_hi = center - 512, center + 512

    motor_limits[motor_id] = {
        'lo': min_limit, 'hi': max_limit,
        'tight_lo': tight_lo, 'tight_hi': tight_hi,
        'mid': (tight_lo + tight_hi) // 2
    }

    packetHandler.write2ByteTxRx(portHandler, motor_id, ADDR_POSITION_P_GAIN, DXL_PID_GAINS[i][0])
    packetHandler.write2ByteTxRx(portHandler, motor_id, ADDR_POSITION_I_GAIN, DXL_PID_GAINS[i][1])
    packetHandler.write2ByteTxRx(portHandler, motor_id, ADDR_POSITION_D_GAIN, DXL_PID_GAINS[i][2])
    packetHandler.write4ByteTxRx(portHandler, motor_id, ADDR_PROFILE_VELOCITY, profile_velocity)
    packetHandler.write4ByteTxRx(portHandler, motor_id, ADDR_PROFILE_ACCELERATION, profile_acceleration)

    print(f"Configured motor {motor_id}: tight [{tight_lo}, {tight_hi}]")

# Enable torque
for motor_id in DXL_ID_MOVE:
    packetHandler.write1ByteTxRx(portHandler, motor_id, ADDR_TORQUE_ENABLE, TORQUE_ENABLE)

# SyncRead: read ALL for observations
for motor_id in DXL_ID_ALL:
    if not groupSyncRead.addParam(motor_id):
        print(f"[ID:{motor_id:03d}] groupSyncRead addparam failed"); sys.exit(1)

# =========================
# Policy + observation state
# =========================
hist_buf = np.zeros((config.history_frames, 40), dtype=np.float32)
object_one_hot = config.object_one_hot
policy = torch.jit.load(TS_POLICY_PATH, map_location="cpu"); policy.eval()

# last-known ticks cache for robust reads
last_known_ticks = {mid: motor_limits[mid]['mid'] for mid in DXL_ID_ALL}
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

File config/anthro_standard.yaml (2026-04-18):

# Configuration for 5-finger anthropomorphic robotic hand control

# Policy Configuration
policy:
  # Default policy path - can be overridden with --policy-path argument
  default_path: "agents/rlgames_5_finger_blind_policy.pt"

# Control Parameters
control:
  act_moving_avg: 0.041666666666666664  # 1.0 / 24.0 - action smoothing factor
  control_hz: 30.0  # Control loop frequency in Hz

# Default Joint Positions (Isaac Lab order)
# Format: [finger1_joints(5), finger2_joints(5), finger3_joints(5), finger4_joints(5)]
# Each finger: [palm_rotation, proximal, middle, distal, fingertip]
joint_positions:
  default_isaac_order: [
    0.0, 0.0, 0.0, 0.0, 0.0,           # Finger 1 (Thumb)
    0.487, 0.487, 0.487, 0.487, 0.487, # Finger 2 (Index)
    1.46, 1.46, 1.46, 1.46, 1.46,      # Finger 3 (Middle)
    1.16, 1.16, 1.16, 1.16, 1.16       # Finger 4 (Ring)
  ]

# Dynamixel Hardware Configuration
dynamixel:
  # Communication Settings
  device_name: "/dev/ttyUSB0"
  baudrate: 3000000
  protocol_version: 2.0
  
  # Motor IDs (20 motors total for 5-finger hand)
  motor_ids: [1, 2, 3, 4, 5, 6, 7, 8, 9, 10, 11, 12, 13, 14, 15, 16, 17, 18, 19, 20]
  palm_ids: [1, 5, 9, 13, 17]  # Palm rotation motors for each finger
  
  # Control Table Addresses (Dynamixel Protocol 2.0)
  addresses:
    torque_enable: 64
    goal_position: 116
    present_position: 132
    min_position_limit: 52
    max_position_limit: 48
    profile_velocity: 112
    profile_acceleration: 108
    position_p_gain: 84
    position_i_gain: 82
    position_d_gain: 80
    firmware_version: 6
    return_delay_time: 9
  
  # Data Lengths
  data_lengths:
    goal_position: 4
    present_position: 4
  
  # Constants
  torque_enable_value: 1
  torque_disable_value: 0
  invalid_u32: 0xFFFFFFFF
  
  # Motion Profile Settings
  profile_velocity: 300      # Velocity limit for trajectory generation
  profile_acceleration: 100  # Acceleration limit for trajectory generation

# Per-Motor Limit Offsets [tight_lo_offset, tight_hi_offset]
# These offsets tighten the operational range within hardware limits
# to prevent mechanical stress and improve safety margins
limit_offsets: [
  [23, -533],    # ID 1  - Finger 1 palm
  [16, -261],    # ID 2  - Finger 1 proximal
  [17, -114],    # ID 3  - Finger 1 middle
  [273, -114],   # ID 4  - Finger 1 distal
  [57, -228],    # ID 5  - Finger 2 palm
  [34, -284],    # ID 6  - Finger 2 proximal
  [34, -114],    # ID 7  - Finger 2 middle
  [228, -171],   # ID 8  - Finger 2 distal
  [57, -114],    # ID 9  - Finger 3 palm
  [34, -284],    # ID 10 - Finger 3 proximal
  [34, -114],    # ID 11 - Finger 3 middle
  [228, -171],   # ID 12 - Finger 3 distal
  [148, -80],    # ID 13 - Finger 4 palm
  [11, -341],    # ID 14 - Finger 4 proximal
  [23, -114],    # ID 15 - Finger 4 middle
  [228, -171],   # ID 16 - Finger 4 distal
  [604, -250],   # ID 17 - Finger 5 palm
  [23, -341],    # ID 18 - Finger 5 proximal
  [34, -125],    # ID 19 - Finger 5 middle
  [228, -171]    # ID 20 - Finger 5 distal
]

# PID Gains [P, I, D] for Each Motor
# Tuned for stable position control with minimal oscillation
pid_gains: [
  [700, 0, 400],    # ID 1  - Finger 1 palm
  [750, 40, 400],   # ID 2  - Finger 1 proximal
  [700, 20, 400],   # ID 3  - Finger 1 middle
  [750, 0, 400],    # ID 4  - Finger 1 distal
  [700, 0, 400],    # ID 5  - Finger 2 palm
  [750, 15, 450],   # ID 6  - Finger 2 proximal
  [800, 5, 400],    # ID 7  - Finger 2 middle
  [750, 0, 400],    # ID 8  - Finger 2 distal
  [700, 0, 450],    # ID 9  - Finger 3 palm
  [700, 50, 400],   # ID 10 - Finger 3 proximal
  [775, 0, 450],    # ID 11 - Finger 3 middle
  [700, 0, 400],    # ID 12 - Finger 3 distal
  [700, 0, 400],    # ID 13 - Finger 4 palm
  [750, 15, 400],   # ID 14 - Finger 4 proximal
  [800, 30, 500],   # ID 15 - Finger 4 middle
  [600, 0, 200],    # ID 16 - Finger 4 distal
  [800, 0, 550],    # ID 17 - Finger 5 palm
  [800, 0, 400],    # ID 18 - Finger 5 proximal
  [800, 0, 450],    # ID 19 - Finger 5 middle
  [800, 0, 450]     # ID 20 - Finger 5 distal
]

# Simulation Parameters
simulation:
  # Joint angle ranges in radians [min, max]
  palm_range: [-0.698, 0.698]    # ±40 degrees for palm rotation
  other_range: [0.0, 1.5708]     # 0-90 degrees for finger joints

# Observation Configuration
observation:
  history_frames: 3              # Number of observation frames to stack
  object_one_hot: [0, 0, 0, 0]  # One-hot encoding for object type (4 object types)

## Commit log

2026-04-18 all robot hand parts
    [CombineJointAssem.SLDASM, Finger.SLDASM, Fingertip_Assem.SLDASM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]
2026-04-20 added robot hand 3,4,5 finger sym
